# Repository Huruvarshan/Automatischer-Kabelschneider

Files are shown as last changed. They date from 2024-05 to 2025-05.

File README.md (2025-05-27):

# Automatischer Kabelschneider (Automatic Cable Cutter)

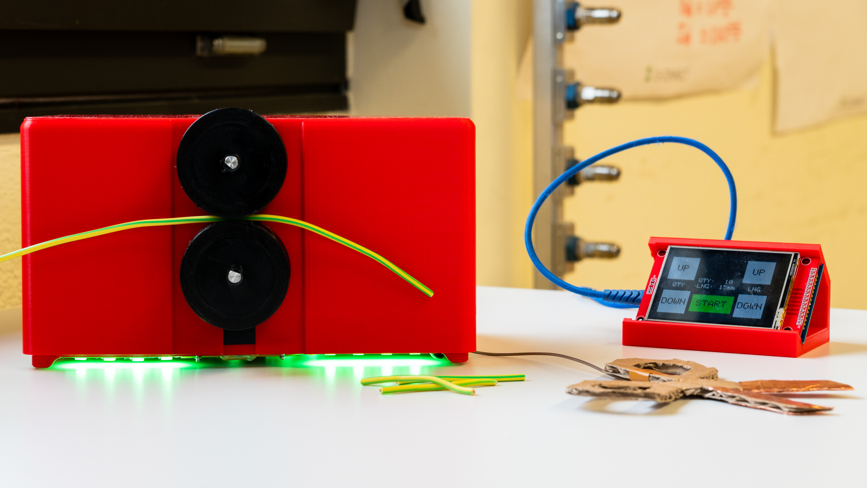
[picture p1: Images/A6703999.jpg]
Project in Action Automatic Cable Cutter


## Overview

The **Automatischer Kabelschneider** is an open-source, programmable device for automatically cutting cables and heat shrink tubes to precise lengths and quantities. Designed for makers, professionals, and hobbyists, it streamlines repetitive workshop tasks, ensuring accuracy, safety, and efficiency in cable and tube preparation.

This repository includes all hardware and software resources needed to build, assemble, and operate the device.

---

## Features

- **Programmable Length & Quantity:**  
  Set the desired length and number of pieces using capacitive buttons and an integrated display.

- **Precision Cutting:**  
  Delivers clean, accurate cuts suitable for various cable and tube diameters.

- **Material Flexibility:**  
  Supports cables, heat shrink tubes, and similar flexible materials.

- **Job Notification:**  
  Visual indicators (LEDs or beacons) signal job progress and completion.

- **Safety:**  
  Built-in overheat protection, a "SawStop"-style emergency system, and run-out sensors to prevent accidents.

---

## Repository Structure

```
Automatischer-Kabelschneider/
├── Hardware/
│   ├── PCB/           # KiCad PCB design files
│   ├── Mechanical/    # Mechanical design files (e.g., 3D models)
│   ├── BOM.md         # Bill of Materials
│   └── README.md      # Hardware documentation
├── Software/
│   ├── AKS_Program/   # Microcontroller firmware (ESP32)
│   │   └── README.md  # Software setup and usage
│   └── README.md      # Software structure and notes
├── Images/            # Project and schematic images
│   └── A6703971.JPG
└── README.md          # Project overview (this file)
```

---

## Getting Started

### 1. Hardware

- Manufacture and assemble the PCB and mechanical parts using files in `/Hardware`.
- Reference the Bill of Materials (`Hardware/BOM.md`) for required components.
- Follow detailed assembly instructions in `Hardware/README.md`.

### 2. Software

- The main firmware for the microcontroller (ESP32) is located in `Software/AKS_Program/`.
- See `Software/AKS_Program/README.md` for build, installation, and configuration steps.
- The firmware controls motors, sensors, and LED feedback, and communicates with the device interface.

### 3. Operation

- Use the device's capacitive interface to configure cut length and quantity.
- Start the automatic cutting process. LEDs provide real-time feedback.
- The machine stops automatically and alerts you when the job is complete.

---

## Documentation

- **Hardware Details:** [Hardware/README.md](Hardware/README.md)
- **Software Instructions:** [Software/AKS_Program/README.md](Software/AKS_Program/README.md)

---

## Contributing

Contributions, bug reports, and suggestions are welcome!  
Please open an issue or submit a pull request via GitHub.

---

## Safety & Disclaimer

- Always follow safety instructions and observe caution while operating the device.
- The authors are not responsible for any injury or damage resulting from use or misuse of this project.

---

## License

This project is licensed under the MIT License.  
See [LICENSE](LICENSE) for details.

---

**Let’s build better tools together!**

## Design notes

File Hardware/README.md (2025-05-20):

# Hardware Documentation

Welcome to the hardware section of the Automatischer Kabelschneider (Automatic Cable Cutter) project.

## PCB Design

- The PCB (Printed Circuit Board) design files are available here:  
  [./PCB/](Automatischer-Kabelschneider/Hardware/PCB/)
  
  a title

## Mechanical Design

- The mechanical design files can be found here:  
  [./Mechanical/](../Mechanical/)  

## Bill of Materials (BOM)

- A complete list of components required for the hardware build is available here:  
  [./BOM.md](./BOM.md)  

## Assembly Instructions

- Step-by-step instructions for assembling the hardware will be provided here.  

## Firmware

- The firmware for running the device is located in the main repository:  
  [../Firmware/](../Firmware/)

## Additional Notes

- Please check that all the referenced files and folders are present in this directory.
- For troubleshooting, questions, or contributions, please open an issue in the main repository.

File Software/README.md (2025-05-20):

# Automatic Cable Cutter – Software

## Overview

This directory contains the software for the Automatic Cable Cutter project.

- **Arduino File:** The Arduino file is intended exclusively for the display unit. It manages and controls the display and user interface.
- **AKS Program:** The AKS program is for the main unit of the cable cutter. It performs the main control functions for the cable cutting process.

## Structure

- `/Arduino/`  
  Code for the display unit (e.g., showing data, handling user input)
- `/AKS/`  
  Main program for controlling and automating the cable cutter

## Usage Notes

- Make sure to upload the Arduino firmware only to the display unit.
- The AKS program should be loaded onto the main control unit (e.g., microcontroller or control computer).
- Both programs are designed to work together, but are not interchangeable.

## Additional Information

- Please make changes or add features in separate branches and submit a pull request.
- If you have questions or encounter issues, create an issue in this repository.
- Documentation for hardware setup and wiring may be provided in additional files or the project Wiki.

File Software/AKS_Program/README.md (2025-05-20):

# AKS-Program

This directory contains the software for the Automatischer Kabelschneider (Automatic Cable Cutter).

## Requirements

- Download the `led-strip.h` library from the Espressif component registry: [led_strip v3.0.1](https://components.espressif.com/components/espressif/led_strip/versions/3.0.1)

## Overview

The code in this folder controls the automatic cable cutting process. Key features include:
- Interfacing with hardware components such as motors and sensors
- Controlling an LED strip for visual feedback
- Providing configuration options for cable length and quantity

## File Structure

- `main.c` (or similar): Main application logic for controlling the cable cutter
- `led-strip.h`: Required library for LED control (see above)
- Additional source and header files for hardware interface and user configuration

## Getting Started

1. Clone this repository.
2. Download and add `led-strip.h` to your project as described above.
3. Build and flash the firmware to your hardware using your preferred ESP32 development environment.

## Usage

- Configure your desired cable length and quantity in the software or via the user interface.
- Start the program to begin the automatic cutting process.
- The LED strip will provide status and progress feedback during operation.

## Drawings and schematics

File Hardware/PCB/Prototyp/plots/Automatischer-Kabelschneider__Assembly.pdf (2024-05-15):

J8 R⁶ | C¹³ | Q4 1 | 2 | 3 | 4 | 5 | 6 1 | 2 | 3 | 4 | 5 | 6 ABCD | ABCD Date: 2024-05-15 KiCad E.D.A. 8.0.2 Size: A4 | Rev: 1.0
File: Automatischer-Kabelschneider.kicad_pcb Sheet: AISLER Project ID: AOEPXYGU ¹⁰k R¹⁴ | 100n C³⁰ TestPoint_Small | TP¹³

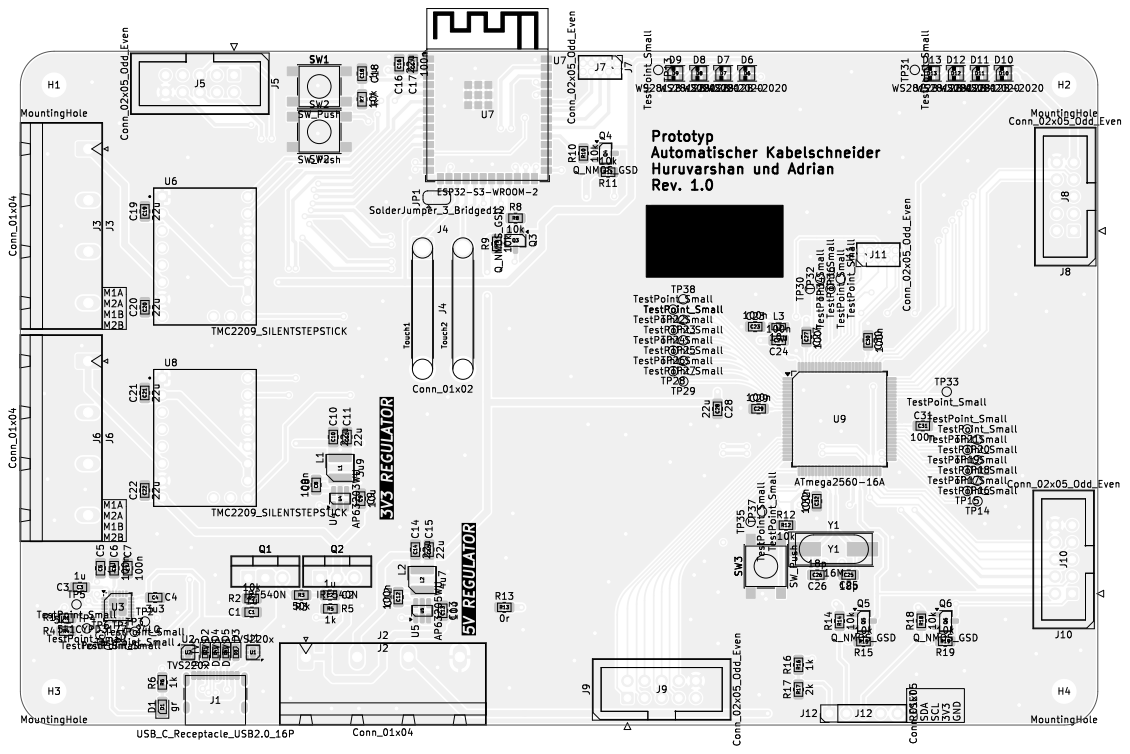
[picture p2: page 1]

1 | 2 | 3 | 4 | 5 | 6

A

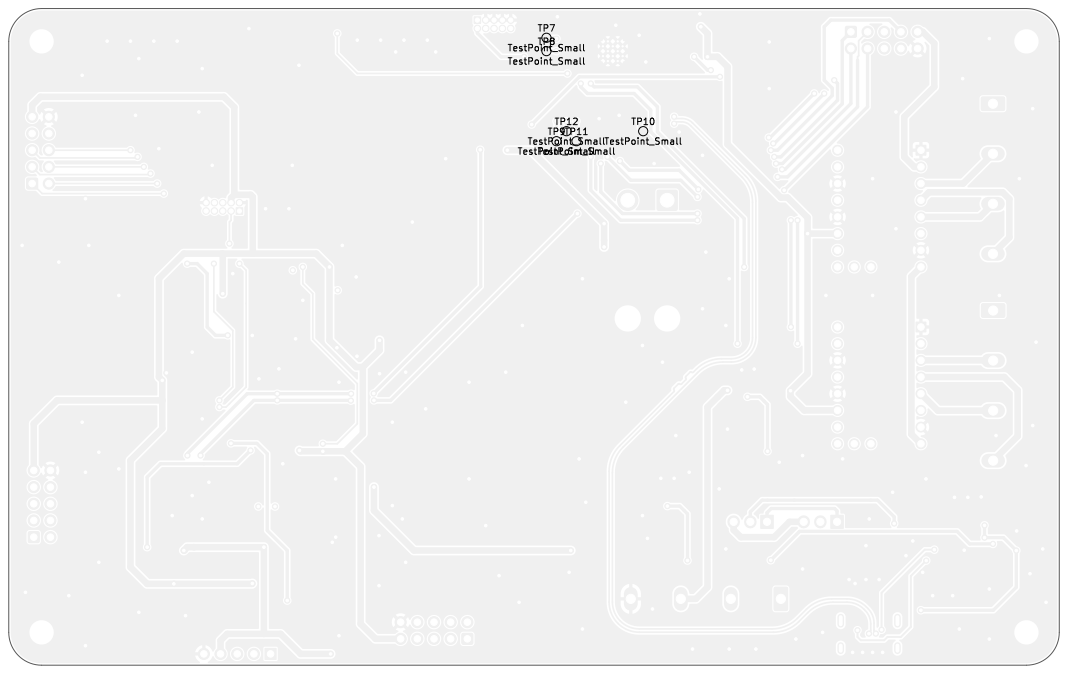
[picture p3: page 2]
D Date: 2024-05-15 KiCad; E.D.A. 8.0.2 Size: A4; Rev: 1.0; File: Automatischer-Kabelschneider.kicad_pcb Sheet: AISLER; Project; ID: AOEPXYGU; TestPoint_Small TP12 TestPoint_Small TP9TP11; TestPoint_Small TP10 TestPoint_Small TP8 TestPoint_Small TP7

Id: 1/1 Title: Prototyp

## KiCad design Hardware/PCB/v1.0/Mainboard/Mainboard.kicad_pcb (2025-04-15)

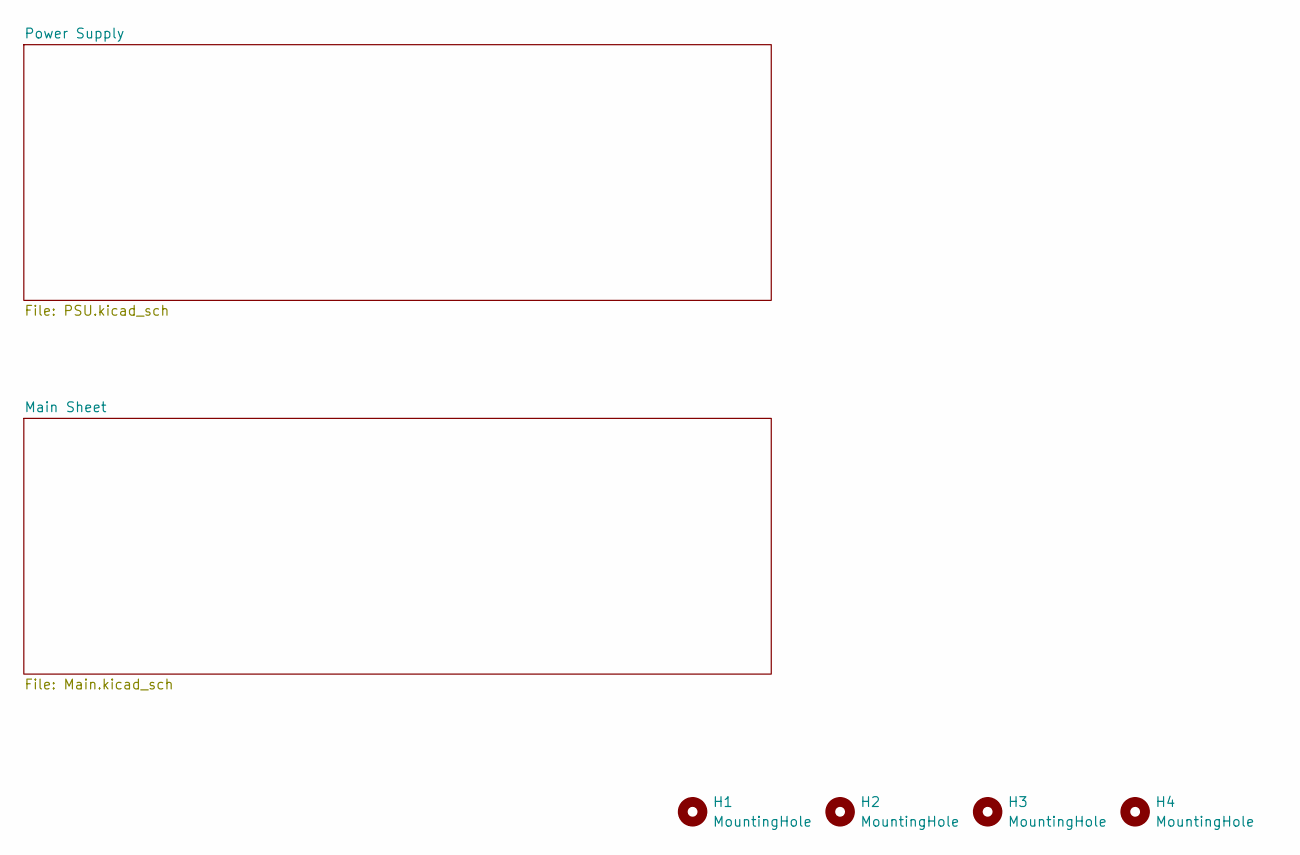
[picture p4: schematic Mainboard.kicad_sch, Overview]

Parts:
H1, H2, H3, H4: MountingHole; MountingHole_3.2mm_M3

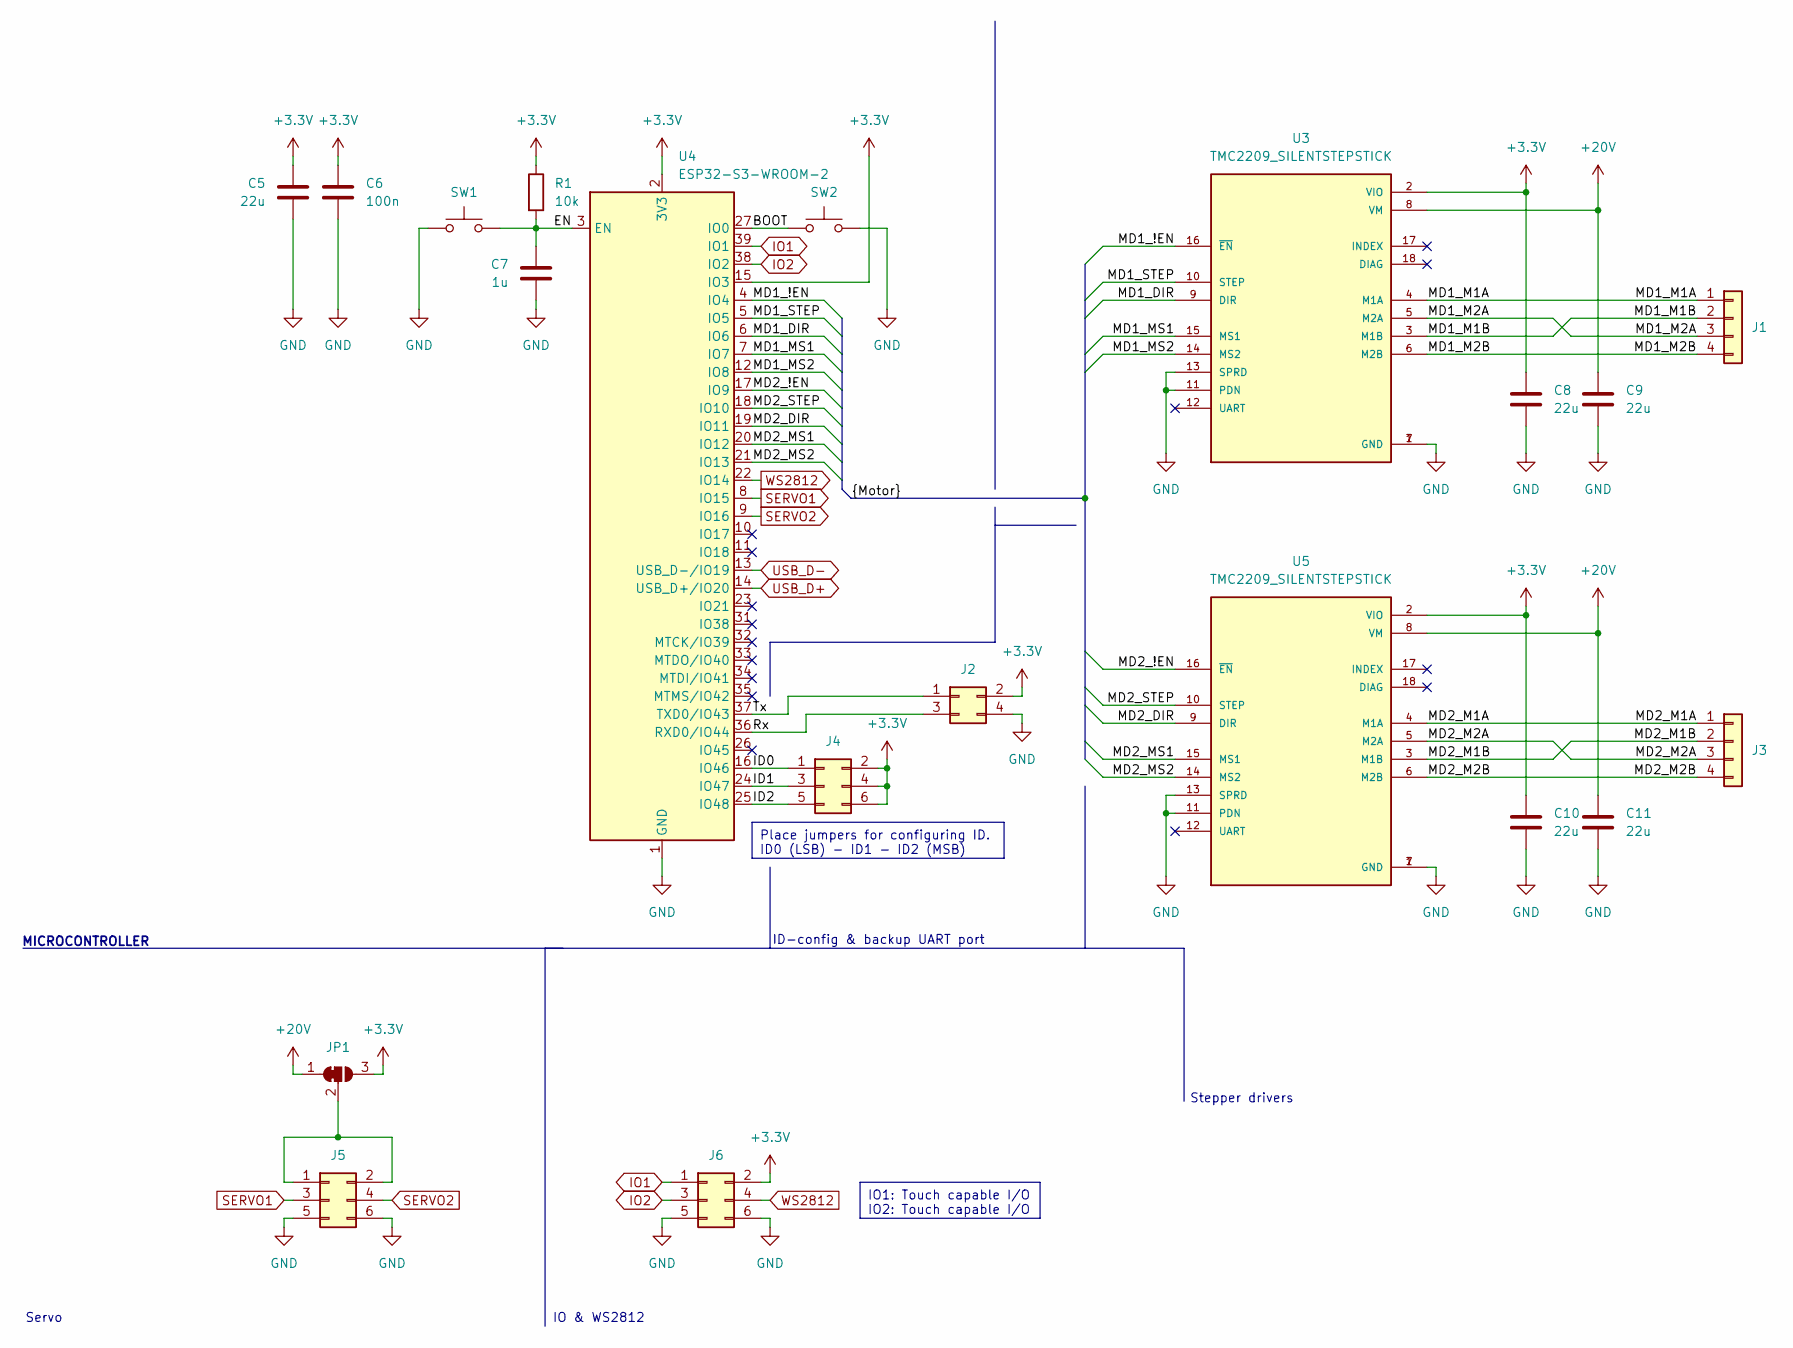
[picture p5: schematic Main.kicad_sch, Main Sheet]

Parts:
C5, C8, C9, C10, C11: 22u; C_0805_2012Metric
C6: 100n; C_0805_2012Metric
C7: 1u; C_0805_2012Metric
J1, J3: Conn_01x04; PhoenixContact_MC_1,5_4-G-3.81_1x04_P3.81mm_Horizontal
J2: Conn_02x02_Odd_Even; PinHeader_2x02_P2.54mm_Vertical
J4, J5, J6: Conn_02x03_Odd_Even; PinHeader_2x03_P2.54mm_Vertical
JP1: SolderJumper_3_Bridged12; SolderJumper-3_P1.3mm_Bridged12_RoundedPad1.0x1.5mm
R1: 10k; R_0805_2012Metric
SW1, SW2: SW_Push; SW_Push_1P1T_NO_6x6mm_H9.5mm
U3, U5: TMC2209_SILENTSTEPSTICK; MODULE_TMC2209_SILENTSTEPSTICK; PARTREV 1.20
U4: ESP32-S3-WROOM-2

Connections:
+3.3V: C5.1, C6.1, C8.1, C10.1, J2.2, J4.2, J4.4, J4.6, J6.2, JP1.3 (B), R1.1, U3.2 (VIO), U4.2 (3V3), U4.15 (IO3), U5.2 (VIO); also elsewhere on the board
+20V: C9.1, C11.1, JP1.1 (A), U3.8 (VM), U5.8 (VM); also elsewhere on the board
/Main Sheet/BOOT: SW2.1, U4.27 (IO0)
/Main Sheet/EN: C7.1, R1.2, SW1.2, U4.3 (EN)
/Main Sheet/ID0: J4.1, U4.16 (IO46)
/Main Sheet/ID1: J4.3, U4.24 (IO47)
/Main Sheet/ID2: J4.5, U4.25 (IO48)
/Main Sheet/MD1_!EN: U3.16 (~EN), U4.4 (IO4)
/Main Sheet/MD1_DIR: U3.9 (DIR), U4.6 (IO6)
/Main Sheet/MD1_M1A: J1.1, U3.4 (M1A)
/Main Sheet/MD1_M1B: J1.2, U3.3 (M1B)
/Main Sheet/MD1_M2A: J1.3, U3.5 (M2A)
/Main Sheet/MD1_M2B: J1.4, U3.6 (M2B)
/Main Sheet/MD1_MS1: U3.15 (MS1), U4.7 (IO7)
/Main Sheet/MD1_MS2: U3.14 (MS2), U4.12 (IO8)
/Main Sheet/MD1_STEP: U3.10 (STEP), U4.5 (IO5)
/Main Sheet/MD2_!EN: U4.17 (IO9), U5.16 (~EN)
/Main Sheet/MD2_DIR: U4.19 (IO11), U5.9 (DIR)
/Main Sheet/MD2_M1A: J3.1, U5.4 (M1A)
/Main Sheet/MD2_M1B: J3.2, U5.3 (M1B)
/Main Sheet/MD2_M2A: J3.3, U5.5 (M2A)
/Main Sheet/MD2_M2B: J3.4, U5.6 (M2B)
/Main Sheet/MD2_MS1: U4.20 (IO12), U5.15 (MS1)
/Main Sheet/MD2_MS2: U4.21 (IO13), U5.14 (MS2)
/Main Sheet/MD2_STEP: U4.18 (IO10), U5.10 (STEP)
/Main Sheet/Rx: J2.3, U4.36 (RXD0/IO44)
/Main Sheet/Tx: J2.1, U4.37 (TXD0/IO43)
GND: C5.2, C6.2, C7.2, C8.2, C9.2, C10.2, C11.2, J2.4, J5.5, J5.6, J6.5, J6.6, SW1.1, SW2.2, U3.1 (GND), U3.7 (GND), U3.11 (PDN), U3.13 (SPRD), U4.1 (GND), U4.40 (GND), U4.41 (GND), U5.1 (GND), U5.7 (GND), U5.11 (PDN), U5.13 (SPRD); also elsewhere on the board
IO1: J6.1, U4.39 (IO1)
IO2: J6.3, U4.38 (IO2)
unnamed: J5.1, J5.2, JP1.2 (C)
SERVO1: J5.3, U4.8 (IO15)
SERVO2: J5.4, U4.9 (IO16)
USB_D+: U4.14 (USB_D+/IO20); also elsewhere on the board
USB_D-: U4.13 (USB_D-/IO19); also elsewhere on the board
WS2812: J6.4, U4.22 (IO14)

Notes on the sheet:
IO1: Touch capable I/O IO2: Touch capable I/O
Place jumpers for configuring ID. ID0 (LSB) - ID1 - ID2 (MSB)
IO & WS2812
Stepper drivers
Servo
ID-config & backup UART port
MICROCONTROLLER

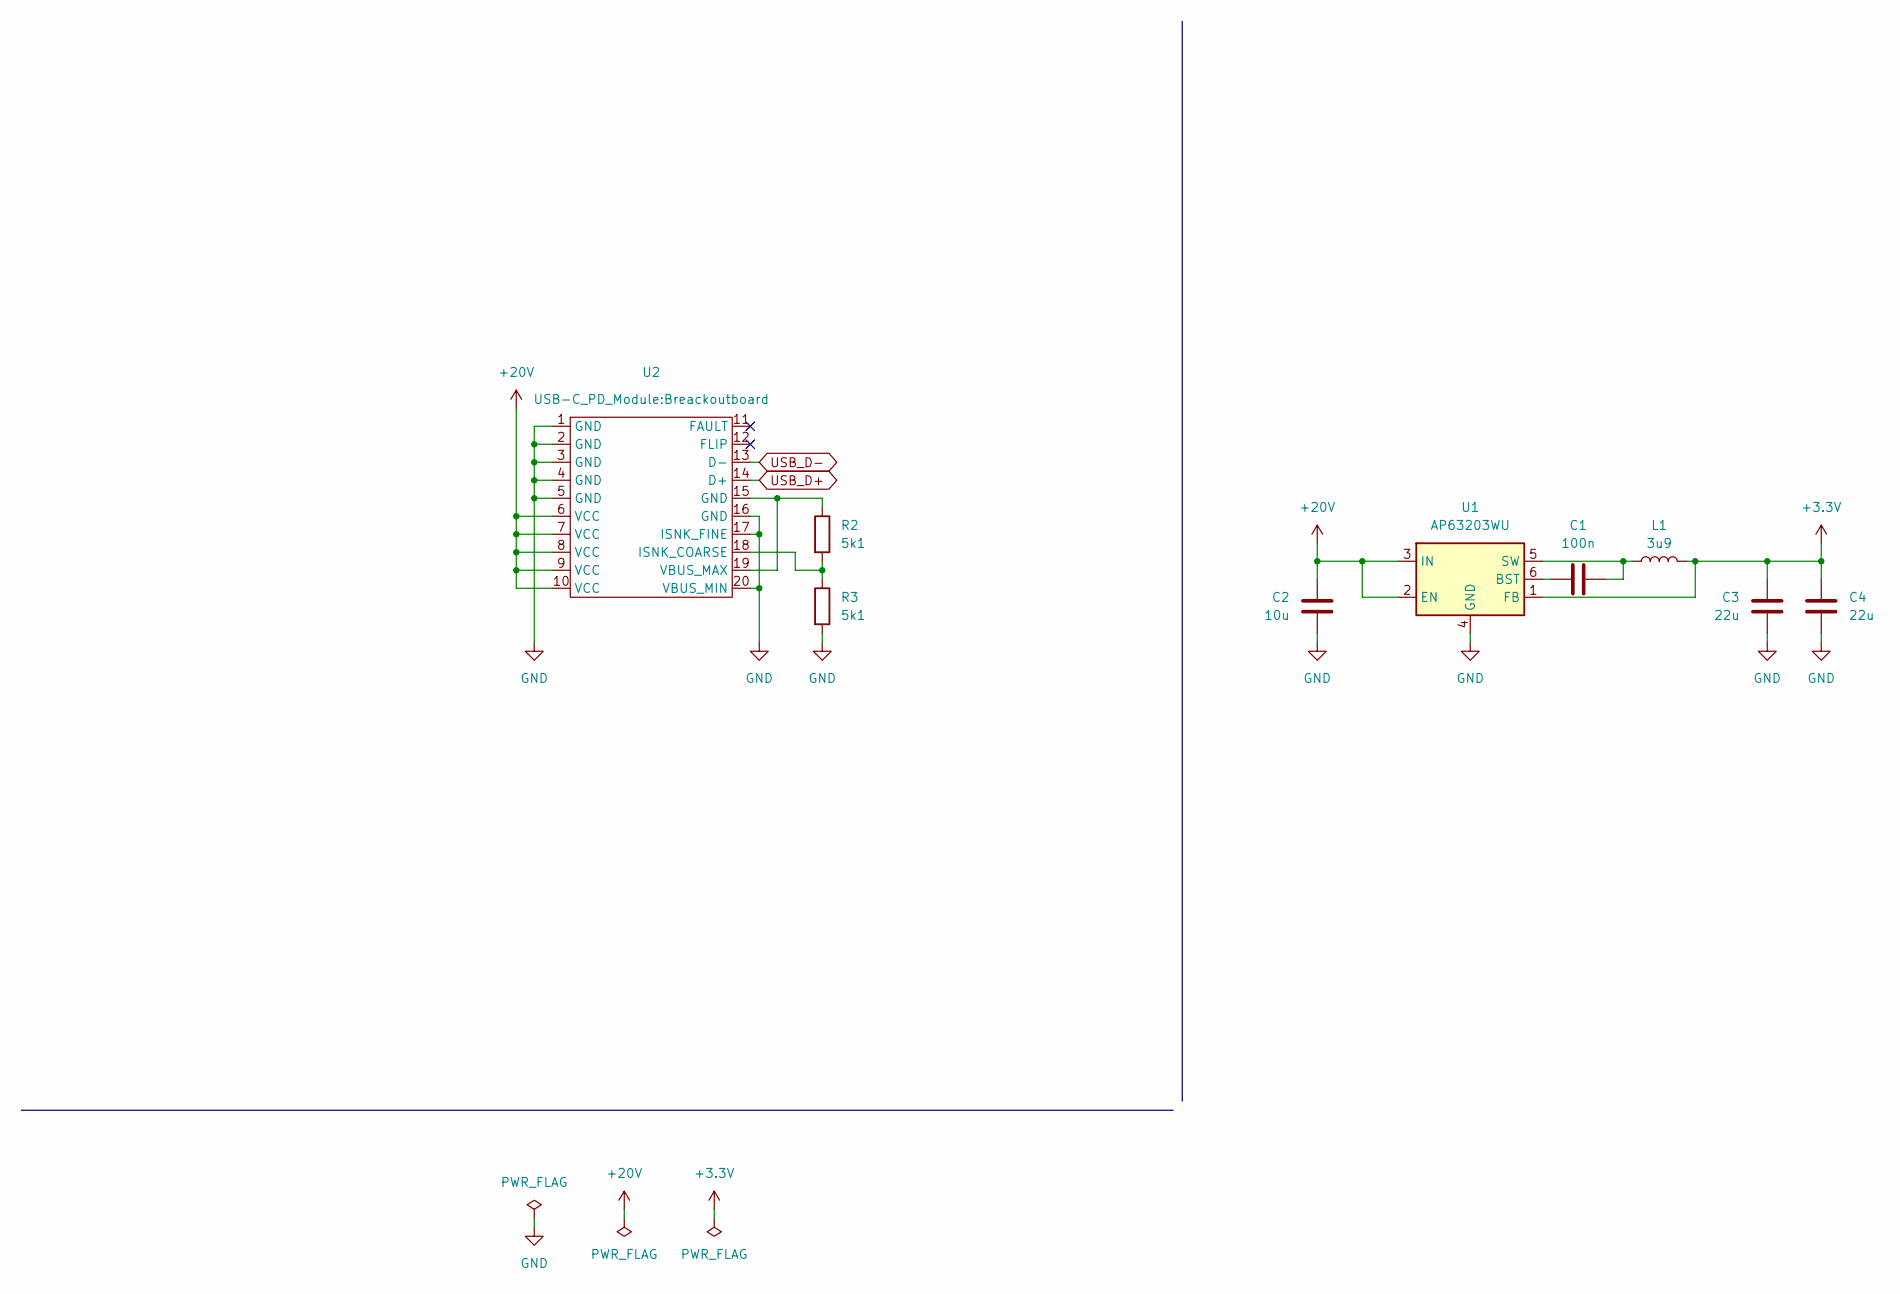
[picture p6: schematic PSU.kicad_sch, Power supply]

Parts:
C1: 100n; C_0805_2012Metric
C2: 10u; C_0805_2012Metric
C3, C4: 22u; C_0805_2012Metric
L1: 3u9; L_Wurth_WE-LQSH-4020
R2, R3: 5k1; R_0805_2012Metric
U1: AP63203WU; TSOT-23-6
U2: Breackoutboard

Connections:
+3.3V: C3.1, C4.1, L1.2, U1.1 (FB); also elsewhere on the board
+20V: C2.1, U1.2 (EN), U1.3 (IN), U2.6 (VCC), U2.7 (VCC), U2.8 (VCC), U2.9 (VCC), U2.10 (VCC); also elsewhere on the board
GND: C2.2, C3.2, C4.2, R3.2, U1.4 (GND), U2.1 (GND), U2.2 (GND), U2.3 (GND), U2.4 (GND), U2.5 (GND), U2.16 (GND), U2.17 (ISNK_FINE), U2.20 (VBUS_MIN); also elsewhere on the board
unnamed: C1.2, U1.6 (BST)
unnamed: C1.1, L1.1, U1.5 (SW)
unnamed: R2.2, R3.1, U2.18 (ISNK_COARSE)
unnamed: R2.1, U2.15 (GND), U2.19 (VBUS_MAX)
USB_D+: U2.14 (D+); also elsewhere on the board
USB_D-: U2.13 (D-); also elsewhere on the board

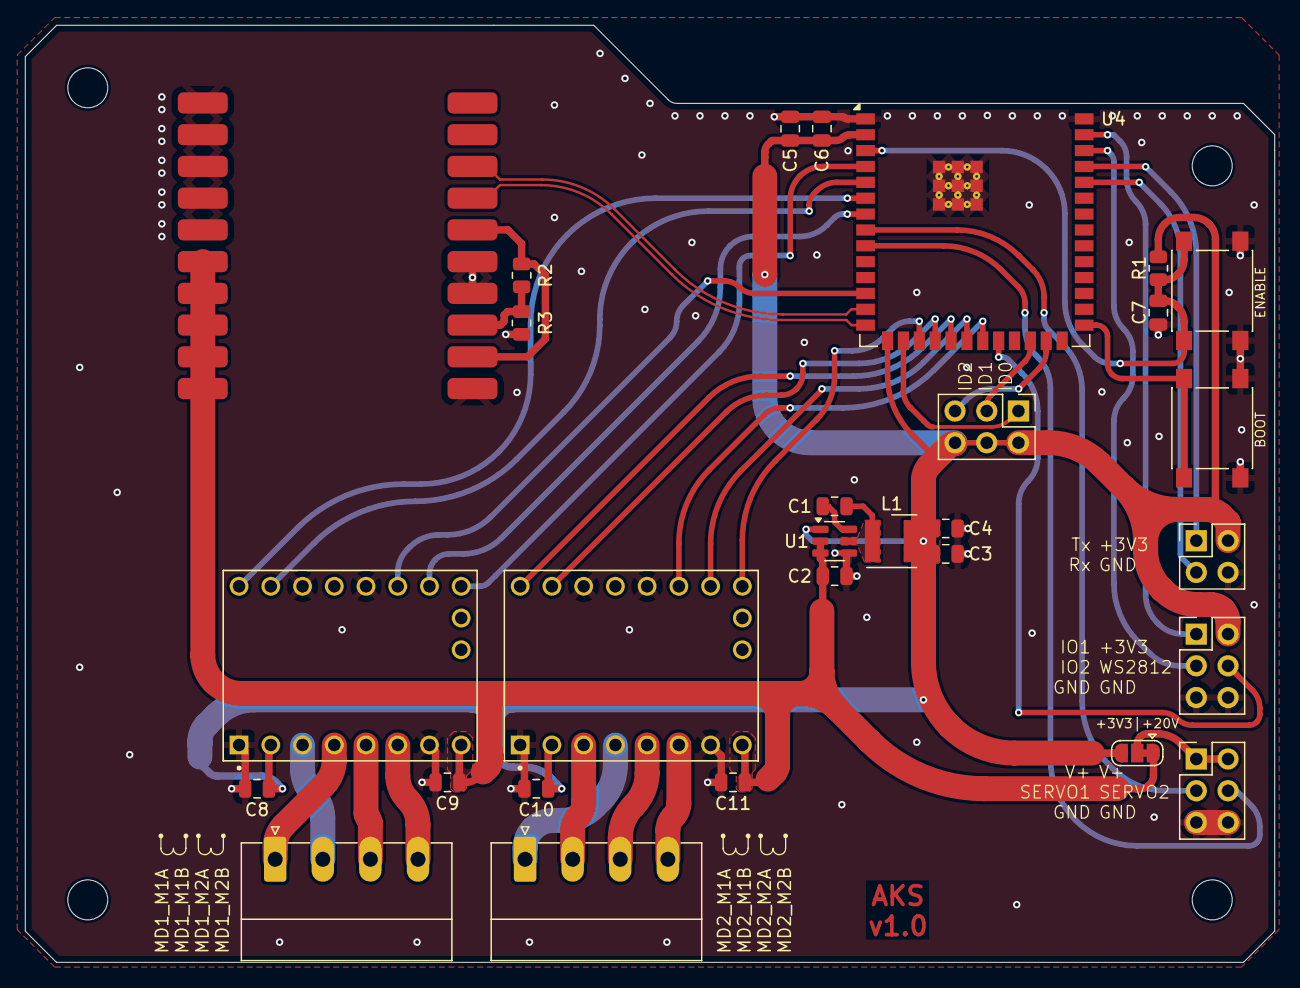
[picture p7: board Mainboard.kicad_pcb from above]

Board: 2 copper layers, 100.0 x 75.0 mm, 33 parts (0 on the bottom side), 40 nets.

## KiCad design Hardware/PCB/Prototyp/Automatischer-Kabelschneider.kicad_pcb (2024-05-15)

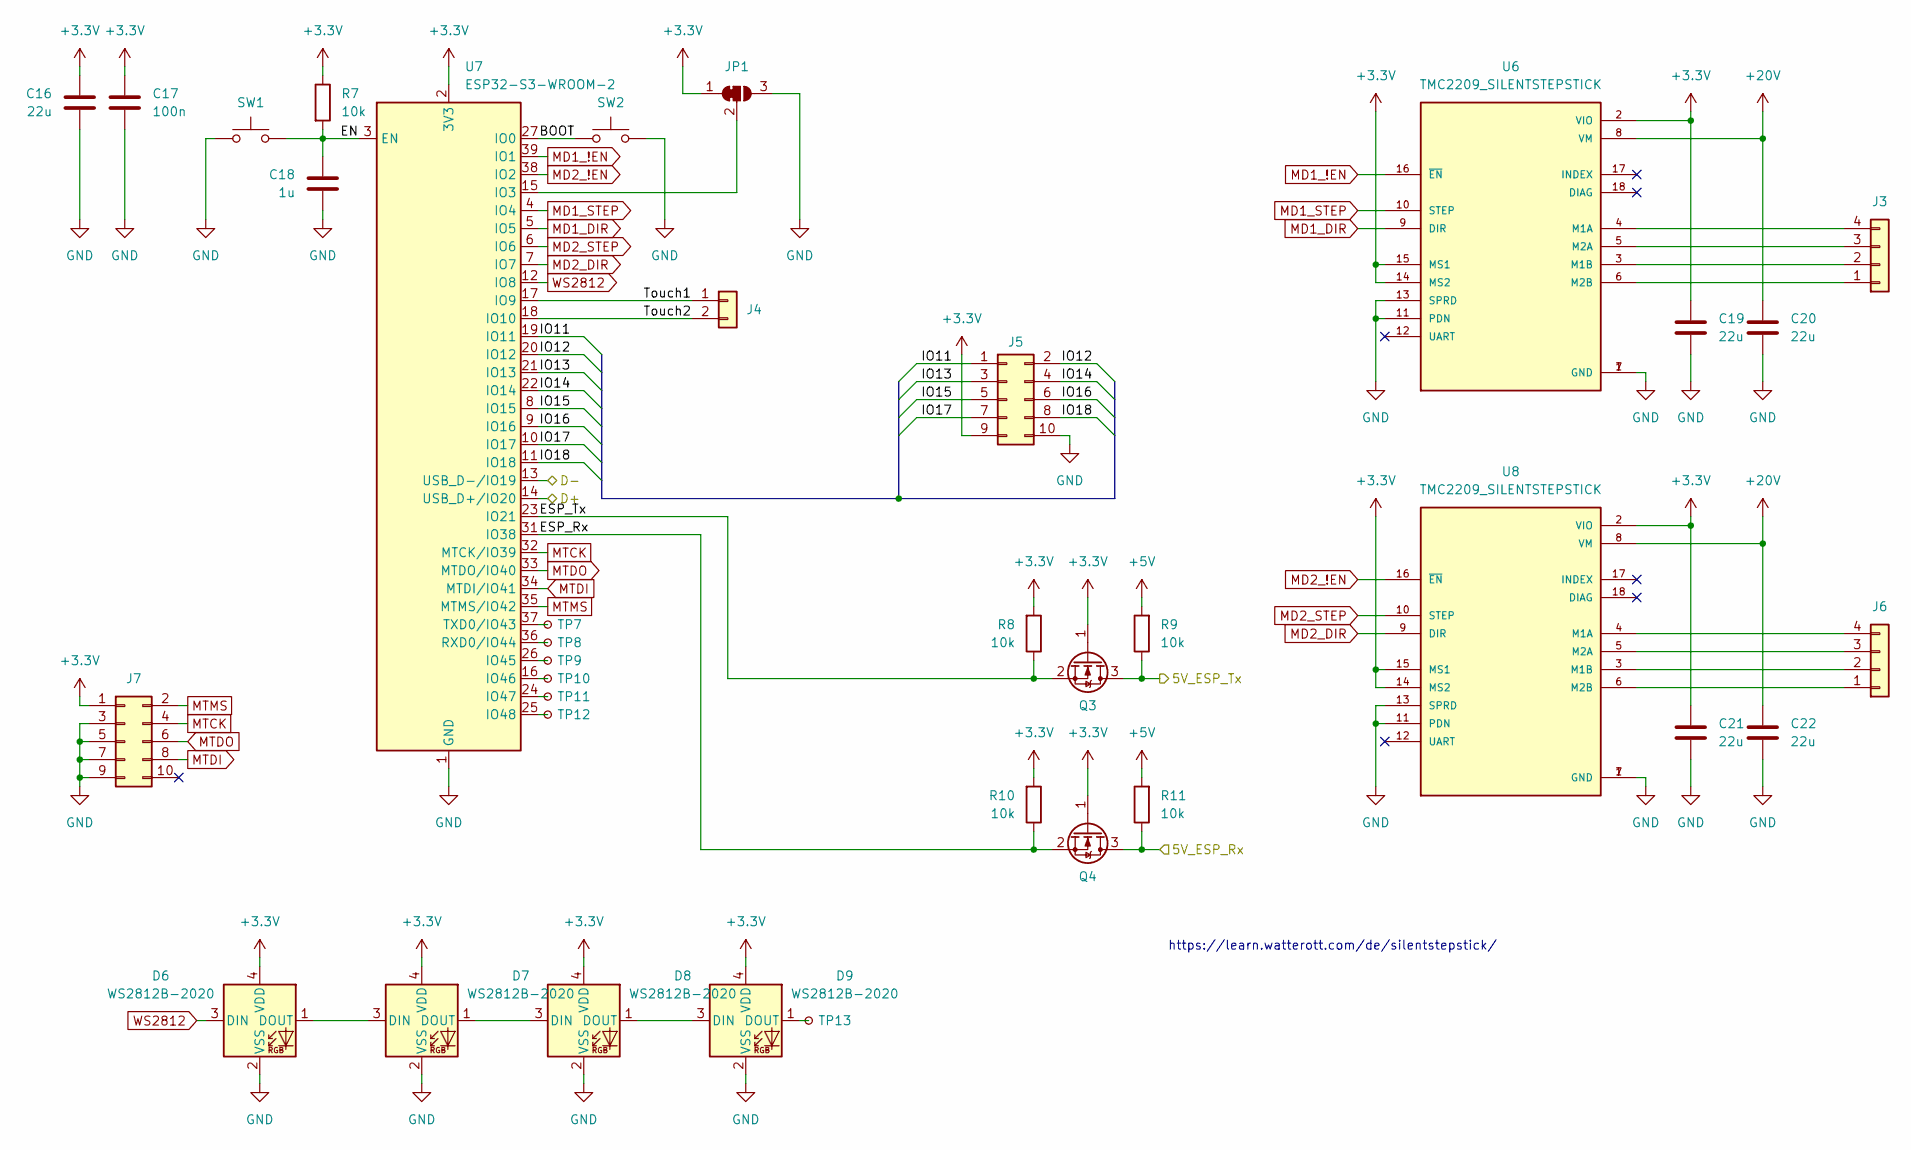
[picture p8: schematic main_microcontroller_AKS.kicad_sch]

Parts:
C16, C19, C20, C21, C22: 22u; C_0805_2012Metric
C17: 100n; C_0805_2012Metric
C18: 1u; C_0805_2012Metric
D6, D7, D8, D9: WS2812B-2020; LED_WS2812B-2020_PLCC4_2.0x2.0mm
J3, J6: Conn_01x04; PhoenixContact_GMSTBA_2,5_4-G-7,62_1x04_P7.62mm_Horizontal
J4: Conn_01x02; SolderWire-1.5sqmm_1x02_P6mm_D1.7mm_OD3mm_Relief
J5: Conn_02x05_Odd_Even; IDC-Header_2x05_P2.54mm_Vertical
J7: Conn_02x05_Odd_Even; PinHeader_2x05_P1.27mm_Vertical
JP1: SolderJumper_3_Bridged12; SolderJumper-3_P1.3mm_Bridged12_RoundedPad1.0x1.5mm
Q3, Q4: Q_NMOS_GSD; TSOT-23
R7, R8, R9, R10, R11: 10k; R_0805_2012Metric
SW1, SW2: SW_Push; SW_Push_1P1T_NO_6x6mm_H9.5mm
TP7, TP8, TP9, TP10, TP11, TP12, TP13: TestPoint_Small; TestPoint_Pad_D1.0mm
U6, U8: TMC2209_SILENTSTEPSTICK; MODULE_TMC2209_SILENTSTEPSTICK; PARTREV 1.20
U7: ESP32-S3-WROOM-2

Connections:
+3.3V: C16.1, C17.1, C19.1, C21.1, D6.4 (VDD), D7.4 (VDD), D8.4 (VDD), D9.4 (VDD), J5.9, J7.1, JP1.1 (A), Q3.1 (G), Q4.1 (G), R7.1, R8.2, R10.2, U6.2 (VIO), U6.14 (MS2), U6.15 (MS1), U7.2 (3V3), U8.2 (VIO), U8.14 (MS2), U8.15 (MS1); also elsewhere on the board
+5V: R9.2, R11.2; also elsewhere on the board
/Main Microcontroller/BOOT: SW2.1, U7.27 (IO0)
/Main Microcontroller/D+: U7.14 (USB_D+/IO20); also elsewhere on the board
/Main Microcontroller/D-: U7.13 (USB_D-/IO19); also elsewhere on the board
/Main Microcontroller/EN: C18.1, R7.2, SW1.2, U7.3 (EN)
/Main Microcontroller/ESP_Rx: Q4.2 (S), R10.1, U7.31 (IO38)
/Main Microcontroller/ESP_Tx: Q3.2 (S), R8.1, U7.23 (IO21)
/Main Microcontroller/IO11: J5.1, U7.19 (IO11)
/Main Microcontroller/IO12: J5.2, U7.20 (IO12)
/Main Microcontroller/IO13: J5.3, U7.21 (IO13)
/Main Microcontroller/IO14: J5.4, U7.22 (IO14)
/Main Microcontroller/IO15: J5.5, U7.8 (IO15)
/Main Microcontroller/IO16: J5.6, U7.9 (IO16)
/Main Microcontroller/IO17: J5.7, U7.10 (IO17)
/Main Microcontroller/IO18: J5.8, U7.11 (IO18)
/Main Microcontroller/Touch1: J4.1, U7.17 (IO9)
/Main Microcontroller/Touch2: J4.2, U7.18 (IO10)
/Slave Microcontroller/ATMEGA_Rx: Q3.3 (D), R9.1; also elsewhere on the board
/Slave Microcontroller/ATMEGA_Tx: Q4.3 (D), R11.1; also elsewhere on the board
GND: C16.2, C17.2, C18.2, C19.2, C20.2, C21.2, C22.2, D6.2 (VSS), D7.2 (VSS), D8.2 (VSS), D9.2 (VSS), J5.10, J7.3, J7.5, J7.7, J7.9, JP1.3 (B), SW1.1, SW2.2, U6.1 (GND), U6.7 (GND), U6.11 (PDN), U6.13 (SPRD), U7.1 (GND), U7.40 (GND), U7.41 (GND), U8.1 (GND), U8.7 (GND), U8.11 (PDN), U8.13 (SPRD); also elsewhere on the board
MD1_!EN: U6.16 (~EN), U7.39 (IO1)
MD1_DIR: U6.9 (DIR), U7.5 (IO5)
MD1_STEP: U6.10 (STEP), U7.4 (IO4)
MD2_!EN: U7.38 (IO2), U8.16 (~EN)
MD2_DIR: U7.7 (IO7), U8.9 (DIR)
MD2_STEP: U7.6 (IO6), U8.10 (STEP)
MTCK: J7.4, U7.32 (MTCK/IO39)
MTDI: J7.8, U7.34 (MTDI/IO41)
MTDO: J7.6, U7.33 (MTDO/IO40)
MTMS: J7.2, U7.35 (MTMS/IO42)
unnamed: D6.1 (DOUT), D7.3 (DIN)
unnamed: D7.1 (DOUT), D8.3 (DIN)
unnamed: D8.1 (DOUT), D9.3 (DIN)
unnamed: D9.1 (DOUT), TP13.1
unnamed: J3.1, U6.6 (M2B)
unnamed: J3.2, U6.3 (M1B)
unnamed: J3.3, U6.5 (M2A)
unnamed: J3.4, U6.4 (M1A)
unnamed: J6.1, U8.6 (M2B)
unnamed: J6.2, U8.3 (M1B)
unnamed: J6.3, U8.5 (M2A)
unnamed: J6.4, U8.4 (M1A)
unnamed: JP1.2 (C), U7.15 (IO3)
unnamed: TP9.1, U7.26 (IO45)
unnamed: TP10.1, U7.16 (IO46)
unnamed: TP11.1, U7.24 (IO47)
unnamed: TP12.1, U7.25 (IO48)
unnamed: TP8.1, U7.36 (RXD0/IO44)
unnamed: TP7.1, U7.37 (TXD0/IO43)
WS2812: D6.3 (DIN), U7.12 (IO8)

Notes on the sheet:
https://learn.watterott.com/de/silentstepstick/

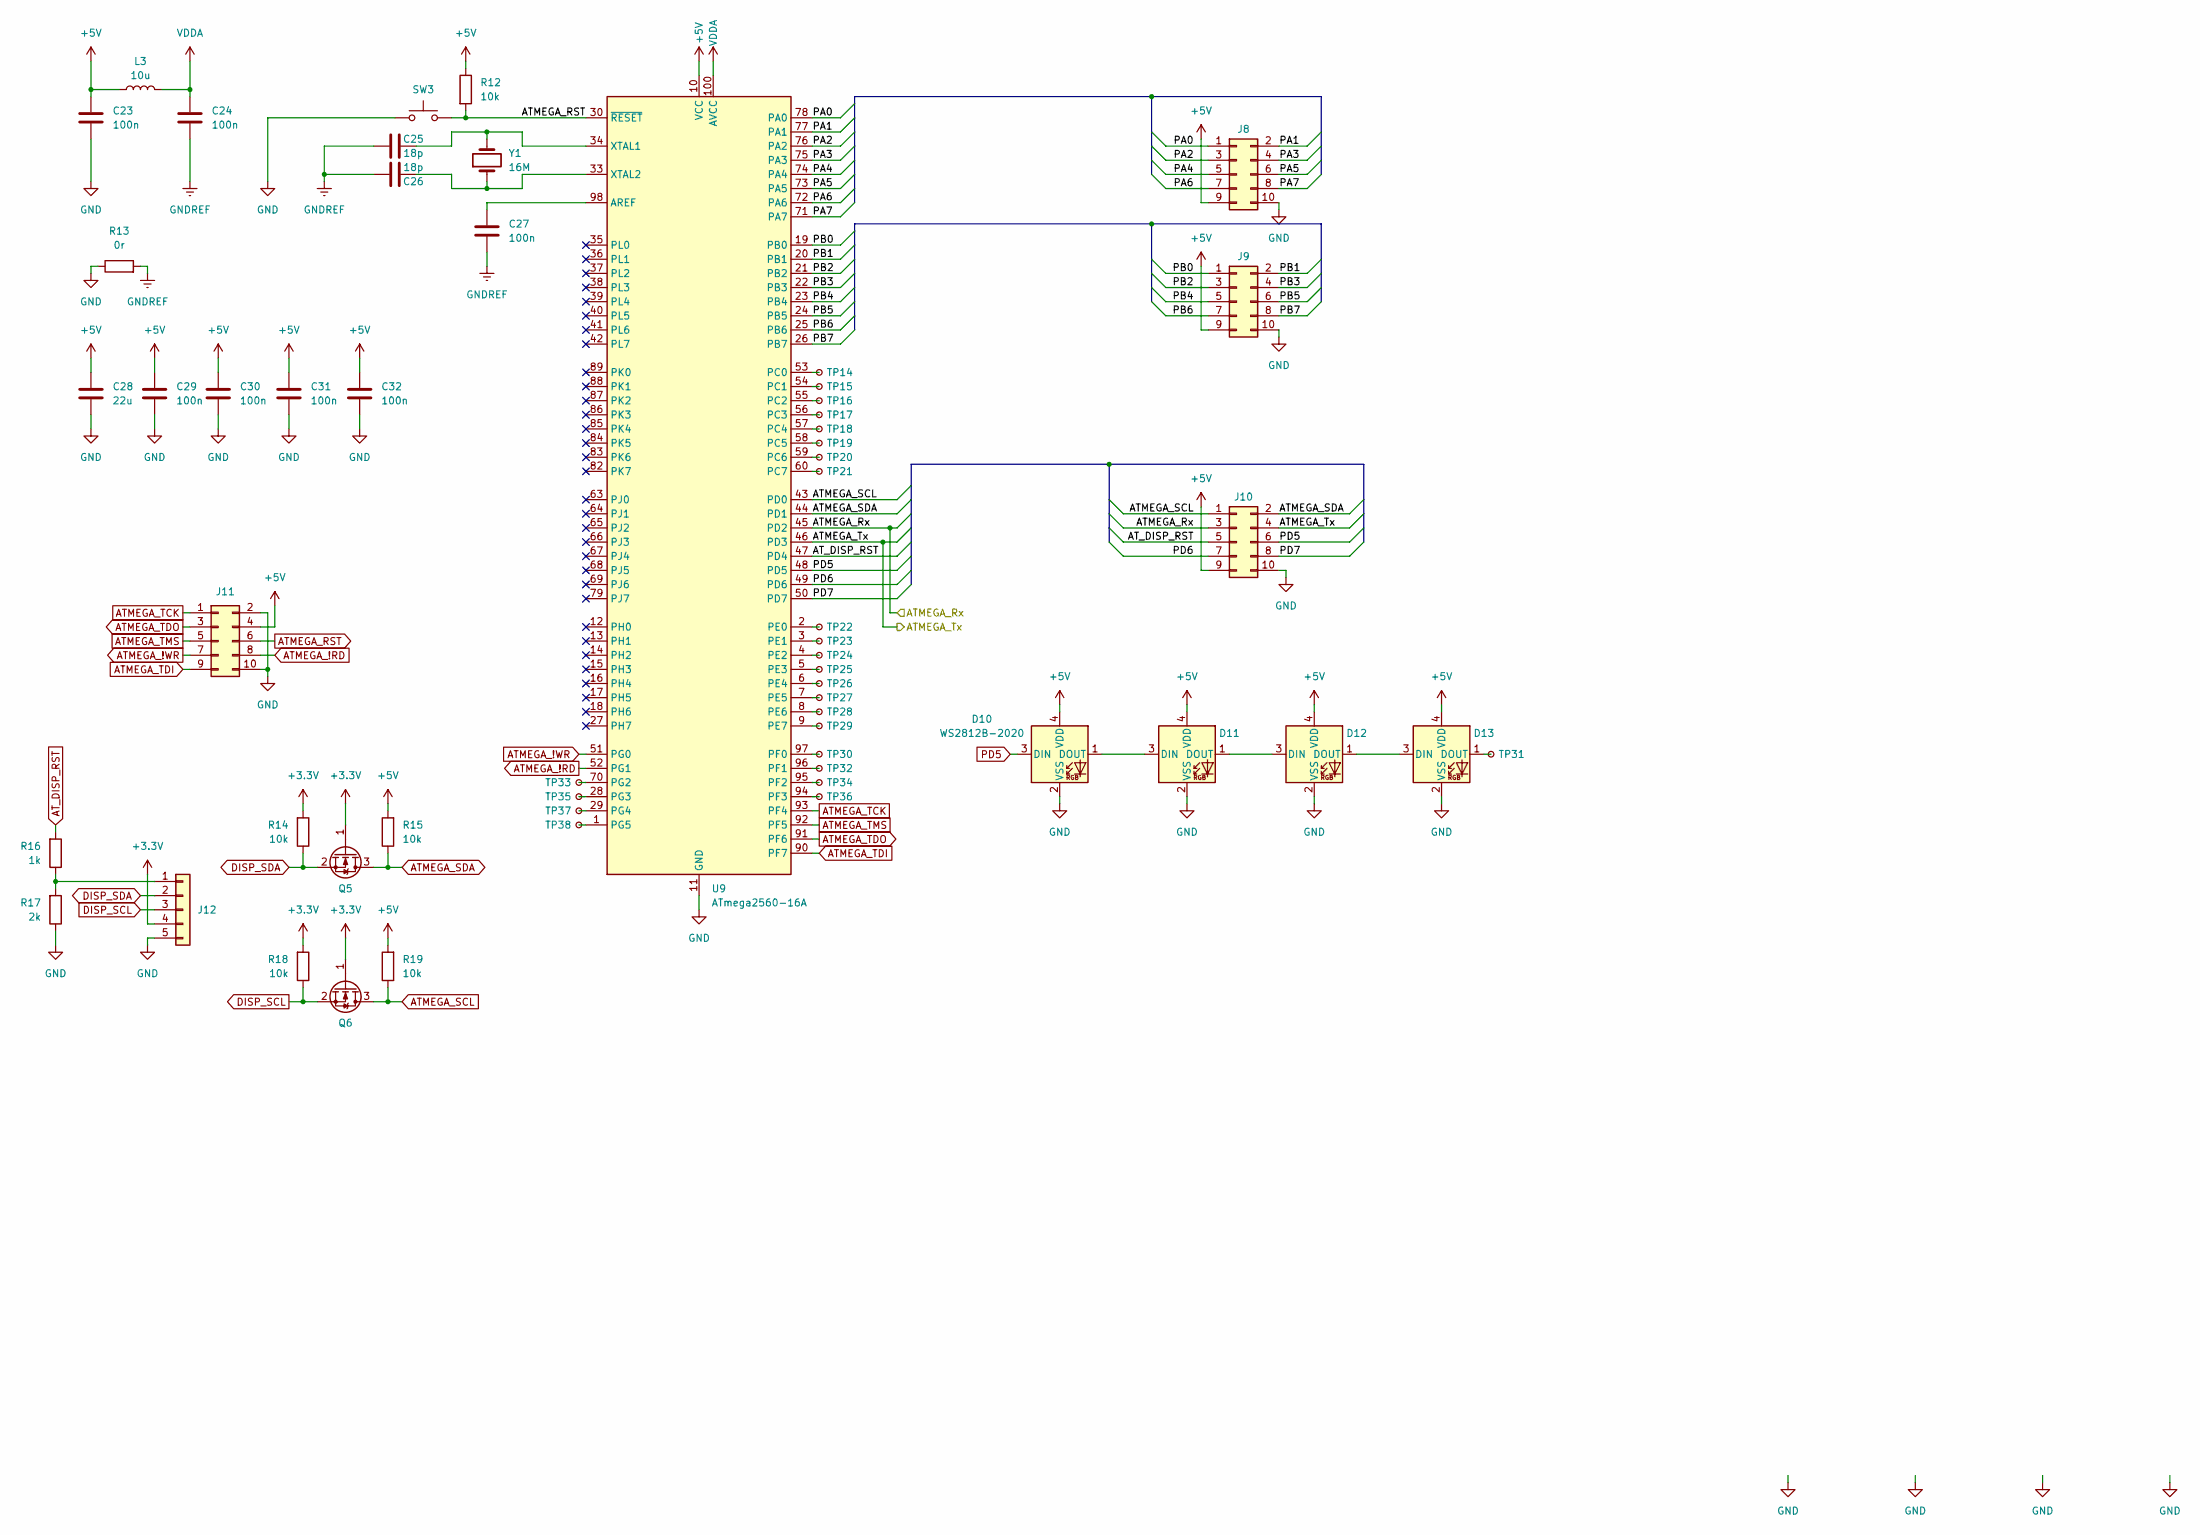
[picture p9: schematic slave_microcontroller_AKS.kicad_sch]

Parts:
C23, C24, C27, C29, C30, C31, C32: 100n; C_0805_2012Metric
C25, C26: 18p; C_0805_2012Metric
C28: 22u; C_0805_2012Metric
D10, D11, D12, D13: WS2812B-2020; LED_WS2812B-2020_PLCC4_2.0x2.0mm
J8, J9, J10: Conn_02x05_Odd_Even; IDC-Header_2x05_P2.54mm_Vertical
J11: Conn_02x05_Odd_Even; PinHeader_2x05_P1.27mm_Vertical
J12: Conn_01x05; PinHeader_1x05_P2.54mm_Vertical
L3: 10u; L_0805_2012Metric
Q5, Q6: Q_NMOS_GSD; TSOT-23
R12, R14, R15, R18, R19: 10k; R_0805_2012Metric
R13: 0r; R_0805_2012Metric
R16: 1k; R_0805_2012Metric
R17: 2k; R_0805_2012Metric
SW3: SW_Push; SW_Push_1P1T_NO_6x6mm_H9.5mm
TP14, TP15, TP16, TP17, TP18, TP19, TP20, TP21, TP22, TP23, TP24, TP25, TP26, TP27, TP28, TP29, TP30, TP31, TP32, TP33, TP34, TP35, TP36, TP37, TP38: TestPoint_Small; TestPoint_Pad_D1.0mm
U9: ATmega2560-16A; TQFP-100_14x14mm_P0.5mm
Y1: 16M; Crystal_SMD_HC49-SD

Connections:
+3.3V: J12.4, Q5.1 (G), Q6.1 (G), R14.2, R18.2; also elsewhere on the board
+5V: C23.1, C28.1, C29.1, C30.1, C31.1, C32.1, D10.4 (VDD), D11.4 (VDD), D12.4 (VDD), D13.4 (VDD), J8.9, J9.9, J10.9, J11.4, L3.1, R12.1, R15.2, R19.2, U9.10 (VCC), U9.31 (VCC), U9.61 (VCC), U9.80 (VCC); also elsewhere on the board
/Slave Microcontroller/ATMEGA_Rx: J10.3, U9.45 (PD2); also elsewhere on the board
/Slave Microcontroller/ATMEGA_Tx: J10.4, U9.46 (PD3); also elsewhere on the board
/Slave Microcontroller/PA0: J8.1, U9.78 (PA0)
/Slave Microcontroller/PA1: J8.2, U9.77 (PA1)
/Slave Microcontroller/PA2: J8.3, U9.76 (PA2)
/Slave Microcontroller/PA3: J8.4, U9.75 (PA3)
/Slave Microcontroller/PA4: J8.5, U9.74 (PA4)
/Slave Microcontroller/PA5: J8.6, U9.73 (PA5)
/Slave Microcontroller/PA6: J8.7, U9.72 (PA6)
/Slave Microcontroller/PA7: J8.8, U9.71 (PA7)
/Slave Microcontroller/PB0: J9.1, U9.19 (PB0)
/Slave Microcontroller/PB1: J9.2, U9.20 (PB1)
/Slave Microcontroller/PB2: J9.3, U9.21 (PB2)
/Slave Microcontroller/PB3: J9.4, U9.22 (PB3)
/Slave Microcontroller/PB4: J9.5, U9.23 (PB4)
/Slave Microcontroller/PB5: J9.6, U9.24 (PB5)
/Slave Microcontroller/PB6: J9.7, U9.25 (PB6)
/Slave Microcontroller/PB7: J9.8, U9.26 (PB7)
/Slave Microcontroller/PD6: J10.7, U9.49 (PD6)
/Slave Microcontroller/PD7: J10.8, U9.50 (PD7)
ATMEGA_!RD: J11.8, U9.52 (PG1)
ATMEGA_!WR: J11.7, U9.51 (PG0)
ATMEGA_RST: J11.6, R12.2, SW3.2, U9.30 (~RESET)
ATMEGA_SCL: J10.1, Q6.3 (D), R19.1, U9.43 (PD0)
ATMEGA_SDA: J10.2, Q5.3 (D), R15.1, U9.44 (PD1)
ATMEGA_TCK: J11.1, U9.93 (PF4)
ATMEGA_TDI: J11.9, U9.90 (PF7)
ATMEGA_TDO: J11.3, U9.91 (PF6)
ATMEGA_TMS: J11.5, U9.92 (PF5)
AT_DISP_RST: J10.5, R16.2, U9.47 (PD4)
DISP_SCL: J12.3, Q6.2 (S), R18.1
DISP_SDA: J12.2, Q5.2 (S), R14.1
GND: C23.2, C28.2, C29.2, C30.2, C31.2, C32.2, D10.2 (VSS), D11.2 (VSS), D12.2 (VSS), D13.2 (VSS), J8.10, J9.10, J10.10, J11.2, J11.10, J12.5, R13.1, R17.1, SW3.1, U9.11 (GND), U9.32 (GND), U9.62 (GND), U9.81 (GND), U9.99 (GND); also elsewhere on the board
GNDREF: C24.2, C25.1, C26.1, C27.2, R13.2
unnamed: D10.1 (DOUT), D11.3 (DIN)
unnamed: D11.1 (DOUT), D12.3 (DIN)
unnamed: D12.1 (DOUT), D13.3 (DIN)
unnamed: D13.1 (DOUT), TP31.1
unnamed: J12.1, R16.1, R17.2
unnamed: C27.1, U9.98 (AREF)
unnamed: TP14.1, U9.53 (PC0)
unnamed: TP15.1, U9.54 (PC1)
unnamed: TP16.1, U9.55 (PC2)
unnamed: TP17.1, U9.56 (PC3)
unnamed: TP18.1, U9.57 (PC4)
unnamed: TP19.1, U9.58 (PC5)
unnamed: TP20.1, U9.59 (PC6)
unnamed: TP21.1, U9.60 (PC7)
unnamed: TP22.1, U9.2 (PE0)
unnamed: TP23.1, U9.3 (PE1)
unnamed: TP24.1, U9.4 (PE2)
unnamed: TP25.1, U9.5 (PE3)
unnamed: TP26.1, U9.6 (PE4)
unnamed: TP27.1, U9.7 (PE5)
unnamed: TP28.1, U9.8 (PE6)
unnamed: TP29.1, U9.9 (PE7)
unnamed: TP30.1, U9.97 (PF0)
unnamed: TP32.1, U9.96 (PF1)
unnamed: TP34.1, U9.95 (PF2)
unnamed: TP36.1, U9.94 (PF3)
unnamed: TP33.1, U9.70 (PG2)
unnamed: TP35.1, U9.28 (PG3)
unnamed: TP37.1, U9.29 (PG4)
unnamed: TP38.1, U9.1 (PG5)
unnamed: C25.2, U9.34 (XTAL1), Y1.2
unnamed: C26.2, U9.33 (XTAL2), Y1.1
PD5: D10.3 (DIN), J10.6, U9.48 (PD5)
VDDA: C24.1, L3.2, U9.100 (AVCC)

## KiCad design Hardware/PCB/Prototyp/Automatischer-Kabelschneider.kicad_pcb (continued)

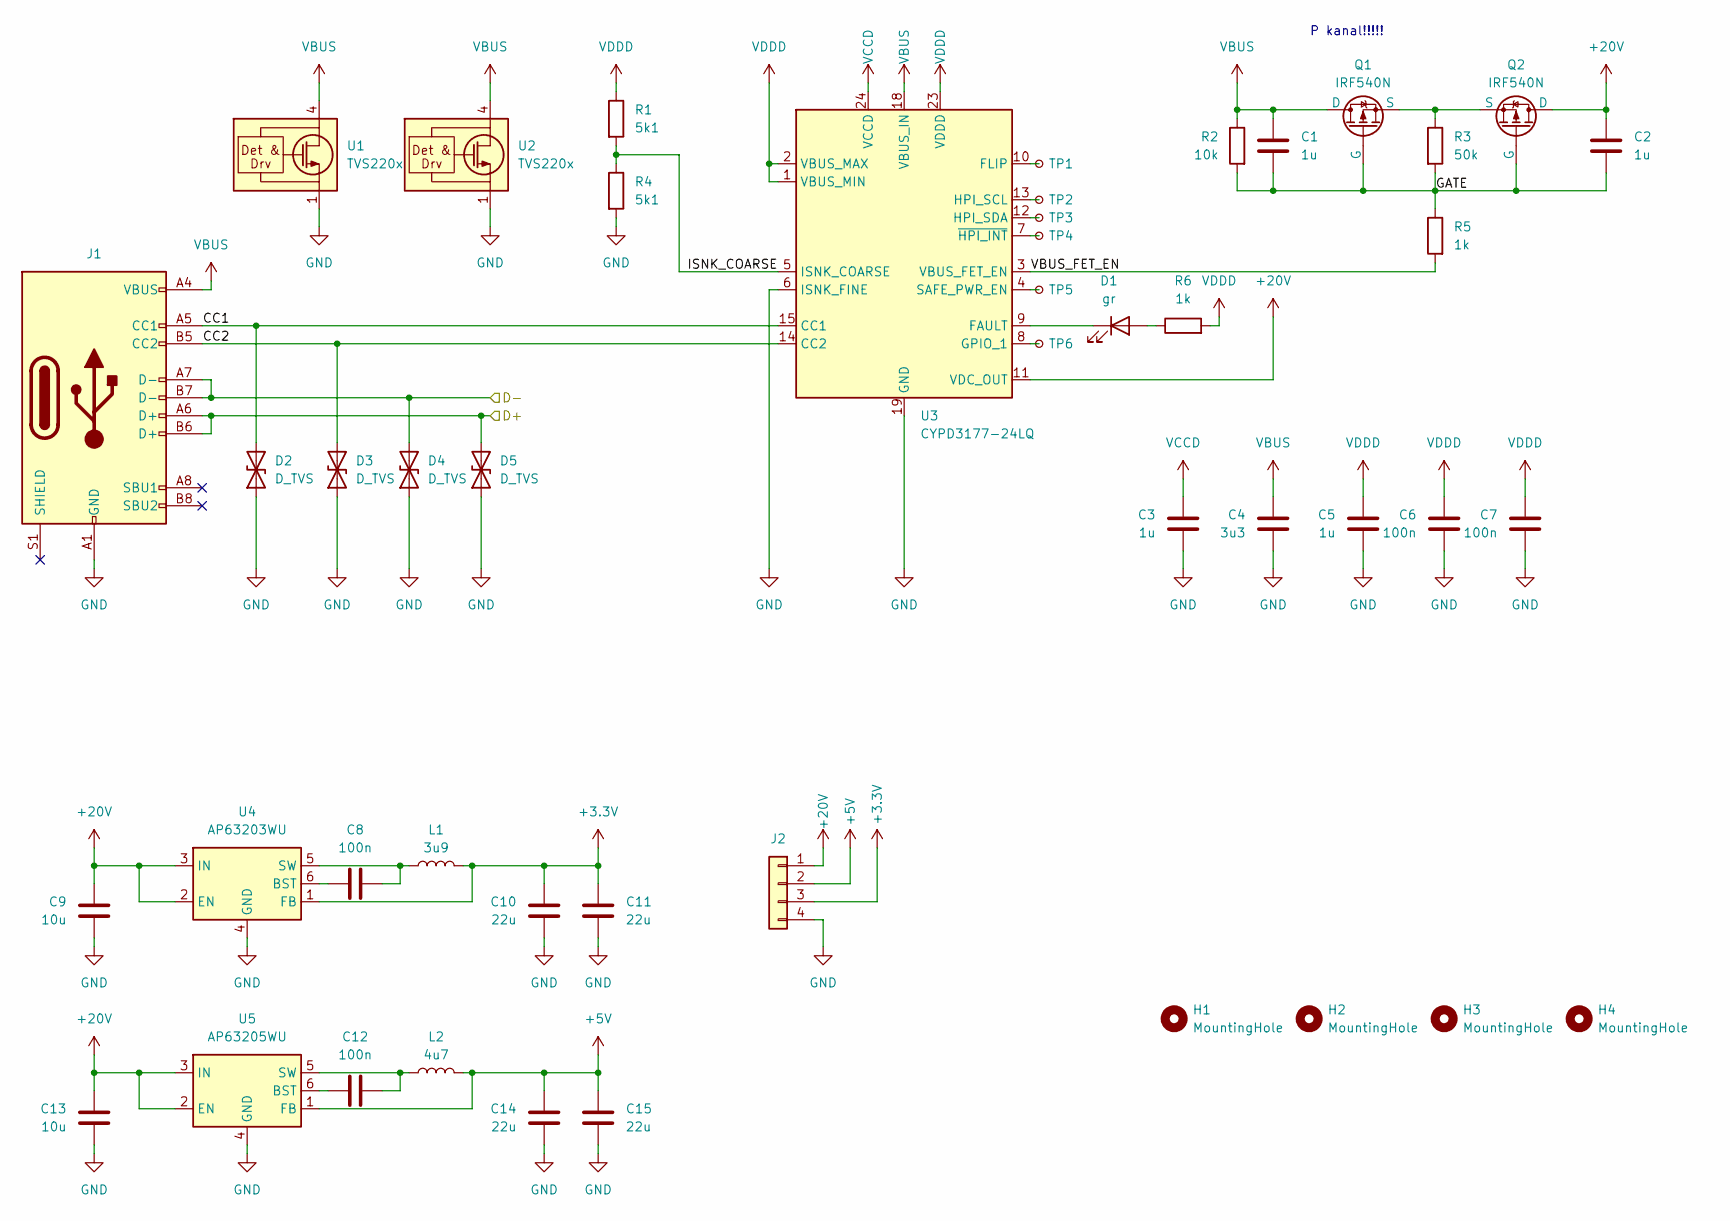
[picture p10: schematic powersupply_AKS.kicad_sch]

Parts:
C1, C2, C3, C5: 1u; C_0805_2012Metric
C4: 3u3; C_0805_2012Metric
C6, C7, C8, C12: 100n; C_0805_2012Metric
C9, C13: 10u; C_0805_2012Metric
C10, C11, C14, C15: 22u; C_0805_2012Metric
D1: gr; D_0805_2012Metric
D2, D3, D4, D5: D_TVS; D_0603_1608Metric
H1, H2, H3, H4: MountingHole; MountingHole_3.2mm_M3
J1: USB_C_Receptacle_USB2.0_16P; USB_C_Receptacle_GCT_USB4105-xx-A_16P_TopMnt_Horizontal
J2: Conn_01x04; PhoenixContact_GMSTBA_2,5_4-G-7,62_1x04_P7.62mm_Horizontal
L1: 3u9; L_Wurth_WE-LQSH-4020
L2: 4u7; L_Wurth_WE-LQSH-4020
Q1, Q2: IRF540N; TO-220-3_Vertical
R1, R4: 5k1; R_0805_2012Metric
R2: 10k; R_0805_2012Metric
R3: 50k; R_0805_2012Metric
R5, R6: 1k; R_0805_2012Metric
TP1, TP2, TP3, TP4, TP5, TP6: TestPoint_Small; TestPoint_Pad_D1.0mm
U1, U2: TVS220x; WSON-6-1EP_2x2mm_P0.65mm_EP1x1.6mm
U3: CYPD3177-24LQ; QFN-24-1EP_4x4mm_P0.5mm_EP2.75x2.75mm
U4: AP63203WU; TSOT-23-6
U5: AP63205WU; TSOT-23-6

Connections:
+3.3V: C10.1, C11.1, J2.3, L1.2, U4.1 (FB); also elsewhere on the board
+5V: C14.1, C15.1, J2.2, L2.2, U5.1 (FB); also elsewhere on the board
/Main Microcontroller/D+: D5.2 (A2), J1.A6 (D+), J1.B6 (D+); also elsewhere on the board
/Main Microcontroller/D-: D4.2 (A2), J1.A7 (D-), J1.B7 (D-); also elsewhere on the board
/Powersupply_AKS/CC1: D2.2 (A2), J1.A5 (CC1), U3.15 (CC1)
/Powersupply_AKS/CC2: D3.2 (A2), J1.B5 (CC2), U3.14 (CC2)
/Powersupply_AKS/ISNK_COARSE: R1.2, R4.1, U3.5 (ISNK_COARSE)
/Powersupply_AKS/VBUS_FET_EN: R5.2, U3.3 (VBUS_FET_EN)
GND: C3.2, C4.2, C5.2, C6.2, C7.2, C9.2, C10.2, C11.2, C13.2, C14.2, C15.2, D2.1 (A1), D3.1 (A1), D4.1 (A1), D5.1 (A1), J1.A1 (GND), J1.A12 (GND), J1.B1 (GND), J1.B12 (GND), J2.4, R4.2, U1.1 (GND), U1.2 (GND), U1.3 (GND), U1.7 (GND), U2.1 (GND), U2.2 (GND), U2.3 (GND), U2.7 (GND), U3.6 (ISNK_FINE), U3.19 (GND), U3.22 (GND), U3.25 (GND), U4.4 (GND), U5.4 (GND); also elsewhere on the board
unnamed: D1.2 (A), R6.1
unnamed: D1.1 (K), U3.9 (FAULT)
unnamed: Q1.3 (S), Q2.3 (S), R3.1
unnamed: TP1.1, U3.10 (FLIP)
unnamed: TP6.1, U3.8 (GPIO_1)
unnamed: TP2.1, U3.13 (HPI_SCL)
unnamed: TP3.1, U3.12 (HPI_SDA)
unnamed: TP5.1, U3.4 (SAFE_PWR_EN)
unnamed: TP4.1, U3.7 (~HPI_INT)
unnamed: C8.2, U4.6 (BST)
unnamed: C8.1, L1.1, U4.5 (SW)
unnamed: C12.2, U5.6 (BST)
unnamed: C12.1, L2.1, U5.5 (SW)
VCCD: C3.1, U3.24 (VCCD)
VDDD: C5.1, C6.1, C7.1, R1.1, R6.2, U3.1 (VBUS_MIN), U3.2 (VBUS_MAX), U3.23 (VDDD)

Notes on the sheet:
P kanal!!!!!

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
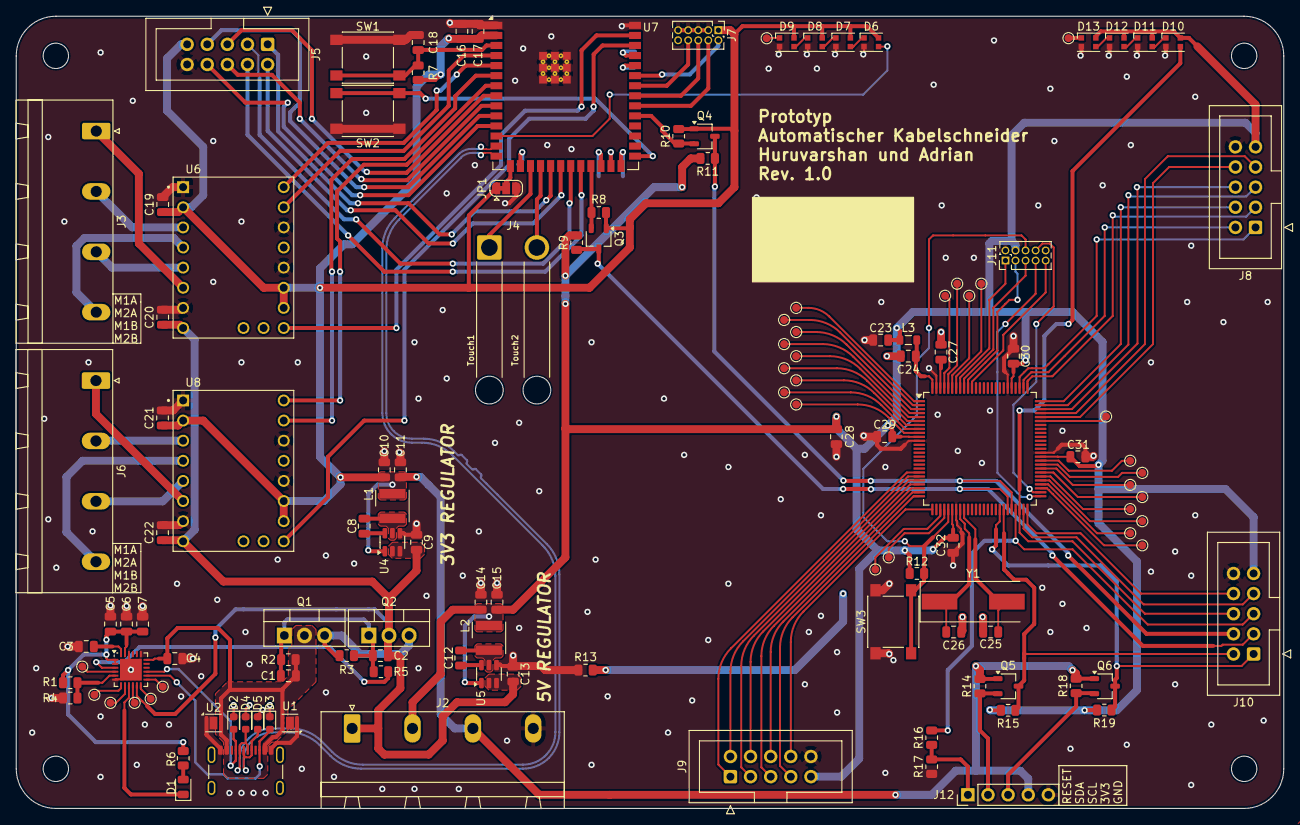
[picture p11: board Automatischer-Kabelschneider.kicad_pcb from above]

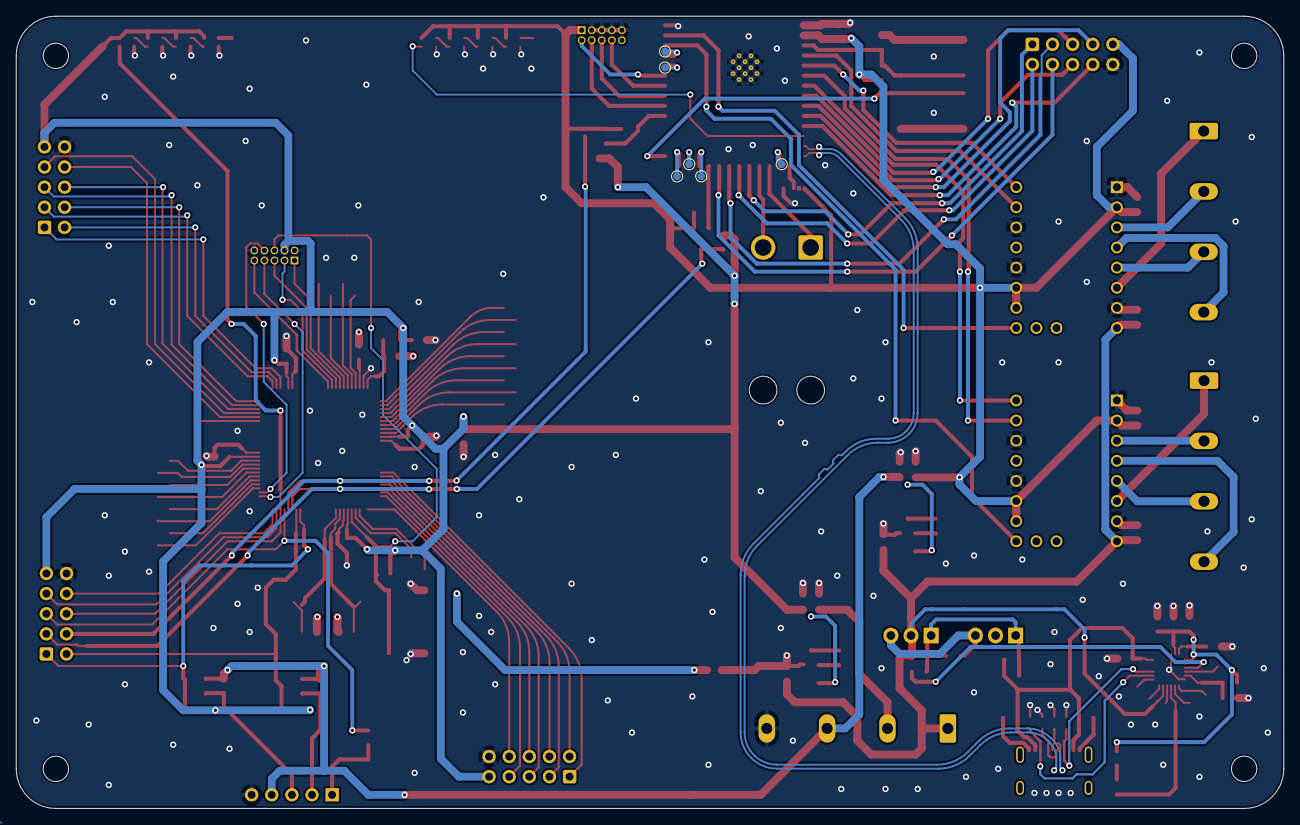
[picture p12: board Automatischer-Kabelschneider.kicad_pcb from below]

Board: 4 copper layers, 160.0 x 100.0 mm, 141 parts (6 on the bottom side), 138 nets.

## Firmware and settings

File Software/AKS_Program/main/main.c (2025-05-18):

#include <stdio.h>
#include "freertos/FreeRTOS.h"
#include "freertos/task.h"
#include "driver/rmt_tx.h"
#include "driver/gpio.h"
#include "esp_log.h"
#include "esp_random.h"
#include "math.h"
#include "esp_wifi.h"
#include "nvs_flash.h"
#include "esp_now.h"
#include "esp_mac.h"
#include "string.h"
#include "stepper_motor_encoder.h"
#include "led_strip.h" 
#include "driver/touch_pad.h"

#define TOUCH_GPIO 1 // GPIO for touch sensor
#define THRESHOLD 80000 // Threshold for touch sensor
#define LED_STRIP_GPIO 14 // GPIO for LED strip
#define LED_STRIP_NUM_LEDS 12 // Number of LEDs in the strip

void EspNowTask(void *pvParameters); 
void StepperTask(void *pvParameters); 
void SafetyTask(void *pvParameters);
void LedTask(void *pvParameters); 

char *mac_to_str(char *buffer, uint8_t *mac);
void on_sent(const uint8_t *mac_addr, esp_now_send_status_t status); 
void on_receive(const esp_now_recv_info_t *esp_now_info, const uint8_t *data, int data_len); 



SemaphoreHandle_t feederStructMutex; 
SemaphoreHandle_t triggerSemaphore;

// Structure for incoming data from the display unit
struct feeder_in_t {
    uint16_t id; // ID from the display unit. Gets from display unit (R)
    uint16_t setAmount; // The set amount configured by the user. Gets from display unit (R) 
    uint16_t setLength; // The set length configured by the user. Gets from display unit (R)
    bool flagStartStop; // Start/Stop flag. Defines if it should stop or continue working. Gets from display unit (R/W) (1 = start, 0 = stop)
    bool flagAbort; // Abort flag. Defines if the job should get aborted. Gets from display unit (R) (1 = abort, 0 = no abort)
} feeder_incoming;

// Structure for outgoing data to the display unit 
struct feeder_out_t {
    uint16_t id; // Sends to display unit (W)
    uint16_t processedAmount; // Sends to display unit (W) 
    bool flagStartStop; // Sends to display unit (W) (1 = start, 0 = stop)
    bool flagAbort; // Sends to display unit (W) (1 = abort, 0 = no abort)
    bool runOut; // Sends to display unit (W) (1 = run out, 0 = no run out)
} feeder_outgoing; 


void app_main(void)
{
    uint8_t my_mac[6];
    char my_mac_str[13];

    feederStructMutex = xSemaphoreCreateMutex(); 
    triggerSemaphore = xSemaphoreCreateBinary(); 

    //feeder.incoming.id = //set to gpio mäuseklavier
    feeder_incoming.setAmount = 0; // Edit to 0 later
    feeder_incoming.setLength = 0; // Edit to 0 later
    feeder_incoming.flagStartStop = 0; 
    feeder_incoming.flagAbort = 0; 

    //feeder_outgoing.id //set to gpio mäuseklavier
    feeder_outgoing.processedAmount = 0; 
    feeder_outgoing.flagStartStop = 1; 
    feeder_outgoing.flagAbort = 0;
    feeder_outgoing.runOut = 0;



    xTaskCreate(StepperTask, "StepperTask", 8192, NULL, 2, NULL);
    xTaskCreate(EspNowTask, "EspNowTask", 8192, NULL, 2, NULL);
    xTaskCreate(SafetyTask, "SafetyTask", 8192, NULL, 3, NULL);
    xTaskCreate(LedTask, "LedTask", 8192, NULL, 1, NULL);
}



void EspNowTask(void *pvParameters){
    uint8_t macDisplay[6] = {0xe4, 0x65, 0xb8, 0x7e, 0x27, 0x98}; // MAC address of the display unit 
    uint8_t my_mac[6];
    char my_mac_str[13];
    // Define a local instance of the feeder_out_t struct for transmission
    struct feeder_out_t feeder_outgoing_data;
    
    esp_efuse_mac_get_default(my_mac);
    ESP_LOGI("MAC_ADDRESS", "My mac %s", mac_to_str(my_mac_str, my_mac));
    
    // Initialize NVS and networking components
    nvs_flash_init();
    ESP_ERROR_CHECK(esp_netif_init());
    ESP_ERROR_CHECK(esp_event_loop_create_default());
    wifi_init_config_t cfg = WIFI_INIT_CONFIG_DEFAULT();
    ESP_ERROR_CHECK(esp_wifi_init(&cfg));
    ESP_ERROR_CHECK(esp_wifi_set_storage(WIFI_STORAGE_RAM));
    ESP_ERROR_CHECK(esp_wifi_set_mode(WIFI_MODE_STA));
    ESP_ERROR_CHECK(esp_wifi_start());
    
    // Initialize ESP-NOW
    ESP_ERROR_CHECK(esp_now_init());
    ESP_ERROR_CHECK(esp_now_register_send_cb(on_sent));
    ESP_ERROR_CHECK(esp_now_register_recv_cb(on_receive));
    
    // Configure peer (display unit)
    esp_now_peer_info_t peer;
    memset(&peer, 0, sizeof(esp_now_peer_info_t));
    memcpy(peer.peer_addr, macDisplay, 6);
    peer.channel = 0;  
    peer.ifidx = ESP_IF_WIFI_STA;
    peer.encrypt = false;
    ESP_ERROR_CHECK(esp_now_add_peer(&peer));

    xSemaphoreTake(feederStructMutex, portMAX_DELAY);

    // Copy the global feeder_outgoing struct data to local struct
    // (assuming feeder_outgoing is a global variable)
    memcpy(&feeder_outgoing_data, &feeder_outgoing, sizeof(struct feeder_out_t));

    // Log the data being sent (optional)
    ESP_LOGI("ESP_NOW", "Sending data: id=%d, processed=%d, start/stop=%d, abort=%d, runOut=%d", 
    feeder_outgoing_data.id, 
    feeder_outgoing_data.processedAmount,
    feeder_outgoing_data.flagStartStop,
    feeder_outgoing_data.flagAbort,
    feeder_outgoing_data.runOut);

    // Send the struct directly through ESP-NOW
    ESP_ERROR_CHECK(esp_now_send(NULL, (uint8_t *)&feeder_outgoing_data, sizeof(struct feeder_out_t)));

    // Release the mutex
    xSemaphoreGive(feederStructMutex);
    
    while (1)
    {
        // Wait for trigger semaphore from another task
        if(xSemaphoreTake(triggerSemaphore, portMAX_DELAY) == pdTRUE){
            // Access shared data with mutex protection
            xSemaphoreTake(feederStructMutex, portMAX_DELAY);
            
            // Copy the global feeder_outgoing struct data to local struct
            // (assuming feeder_outgoing is a global variable)
            memcpy(&feeder_outgoing_data, &feeder_outgoing, sizeof(struct feeder_out_t));
            
            // Log the data being sent (optional)
            ESP_LOGI("ESP_NOW", "Sending data: id=%d, processed=%d, start/stop=%d, abort=%d, runOut=%d", 
                   feeder_outgoing_data.id, 
                   feeder_outgoing_data.processedAmount,
                   feeder_outgoing_data.flagStartStop,
                   feeder_outgoing_data.flagAbort,
                   feeder_outgoing_data.runOut);
            
            // Send the struct directly through ESP-NOW
            ESP_ERROR_CHECK(esp_now_send(NULL, (uint8_t *)&feeder_outgoing_data, sizeof(struct feeder_out_t)));
            
            // Release the mutex
            xSemaphoreGive(feederStructMutex);
           
            // Delay to prevent flooding the network
            //vTaskDelay(pdMS_TO_TICKS(1000));
        }
    }
}

void on_sent(const uint8_t *mac_addr, esp_now_send_status_t status)
{
    xSemaphoreTake(feederStructMutex, portMAX_DELAY); //Take MUTEX to access the feeder struct

    char buffer[13];
    switch (status)
    {
    case ESP_NOW_SEND_SUCCESS:
        ESP_LOGI("MAC_ADDRESS", "message sent to %s", mac_to_str(buffer, (uint8_t *)mac_addr));
        break;
    case ESP_NOW_SEND_FAIL:
        ESP_LOGE("MAC_ADDRESS", "message sent to %s failed", mac_to_str(buffer, (uint8_t *)mac_addr));
        break;
    }

    xSemaphoreGive(feederStructMutex); //Give MUTEX to allow other tasks to access the feeder struct
}

void on_receive(const esp_now_recv_info_t *esp_now_info, const uint8_t *data, int data_len)
{
    // Take mutex to safely access the shared feeder struct
    xSemaphoreTake(feederStructMutex, portMAX_DELAY);
   
    // Log the MAC address of the sender
    ESP_LOGI("MAC_ADDRESS", "Got message from " MACSTR, MAC2STR(esp_now_info->src_addr));
   
    // Check if the data size matches our expected struct size
    if (data_len == sizeof(struct feeder_in_t)) {
        struct feeder_in_t temp_incoming;
       
        // Cast the received data to our temp struct
        memcpy(&temp_incoming, data, sizeof(struct feeder_in_t));
        
        // Check if this is a new job (different ID or different setAmount)
        if (temp_incoming.id != feeder_incoming.id || 
            temp_incoming.setAmount != feeder_incoming.setAmount) {
            // New job detected, reset the processed amount counter
            feeder_outgoing.processedAmount = 0;
            ESP_LOGI("ESP_NOW", "New job detected. Resetting processed amount.");
        }
        // The original check is still useful for when the job completes
        else if (feeder_outgoing.processedAmount >= feeder_incoming.setAmount) {
            // Job is complete, reset the counter for the new job
            feeder_outgoing.processedAmount = 0;
            ESP_LOGI("ESP_NOW", "Previous job complete. Resetting processed amount for new job.");
        }
       
        // Now copy to our global struct
        memcpy(&feeder_incoming, &temp_incoming, sizeof(struct feeder_in_t));
       
        // Log the received data for debugging
        ESP_LOGI("ESP_NOW", "Received struct data: id=%d, setAmount=%d, setLength=%d, startStop=%d, abort=%d",
               feeder_incoming.id,
               feeder_incoming.setAmount,
               feeder_incoming.setLength,
               feeder_incoming.flagStartStop,
               feeder_incoming.flagAbort);
    } else {
        // Handle unexpected data size
        ESP_LOGW("ESP_NOW", "Received data with unexpected size: %d bytes (expected %d bytes)",
                data_len, sizeof(struct feeder_in_t));
    }
   
    // Release the mutex
    xSemaphoreGive(feederStructMutex);
}

char *mac_to_str(char *buffer, uint8_t *mac)
{
    // Make sure the buffer is properly initialized
    memset(buffer, 0, 18);  // Clear buffer (allocate at least 18 bytes for the buffer)
    
    // Format MAC address with proper null termination
    snprintf(buffer, 18, MACSTR, MAC2STR(mac));
    
    return buffer;
}

void StepperTask(void *pvParameters){
    // Tag for logging messages from the Stepper Task
    static const char *STEPPER_TAG = "STEPPER TASK";

    // Initialize GPIO pins for EN (Enable), DIR (Direction), and Microstep settings (MS1, MS2)
    ESP_LOGI(STEPPER_TAG, "Initialize EN + DIR GPIO");
    gpio_config_t en_dir_gpio_config = {
        .mode = GPIO_MODE_OUTPUT, // Set as output mode
        .intr_type = GPIO_INTR_DISABLE, // Disable interrupts
        .pin_bit_mask = 1ULL << STEP_MOTOR_GPIO_DIR | 1ULL << STEP_MOTOR_GPIO_EN | 1ULL << STEP_MOTOR_GPIO_MS1 | 1ULL << STEP_MOTOR_GPIO_MS2, // GPIO pins for motor control
    };
    ESP_ERROR_CHECK(gpio_config(&en_dir_gpio_config));

    // Set microstepping mode (MS1 and MS2 pins)
    gpio_set_level(STEP_MOTOR_GPIO_MS1, 1); // Enable MS1
    gpio_set_level(STEP_MOTOR_GPIO_MS2, 1); // Enable MS2

    // Create RMT (Remote Control) TX channel for stepper motor control
    ESP_LOGI(STEPPER_TAG, "Create RMT TX channel");
    rmt_channel_handle_t motor_chan = NULL;
    rmt_tx_channel_config_t tx_chan_config = {
        .clk_src = RMT_CLK_SRC_DEFAULT, // Select default clock source
        .gpio_num = STEP_MOTOR_GPIO_STEP, // GPIO pin for STEP signal
        .mem_block_symbols = 64, // Memory block size
        .resolution_hz = STEP_MOTOR_RESOLUTION_HZ, // RMT resolution in Hz
        .trans_queue_depth = 10, // Transaction queue depth
    };
    ESP_ERROR_CHECK(rmt_new_tx_channel(&tx_chan_config, &motor_chan));

    // Set motor spin direction
    ESP_LOGI(STEPPER_TAG, "Set spin direction");
    gpio_set_level(STEP_MOTOR_GPIO_DIR, STEP_MOTOR_SPIN_DIR_CLOCKWISE); // Set direction to clockwise

    // Enable the stepper motor
    ESP_LOGI(STEPPER_TAG, "Enable step motor");
    gpio_set_level(STEP_MOTOR_GPIO_EN, STEP_MOTOR_ENABLE_LEVEL); // Enable motor driver

    // Create motor encoders for acceleration, uniform speed, and deceleration phases
    ESP_LOGI(STEPPER_TAG, "Create motor encoders");

    // Encoder for acceleration phase
    stepper_motor_curve_encoder_config_t accel_encoder_config = {
        .resolution = STEP_MOTOR_RESOLUTION_HZ, // Encoder resolution
        .sample_points = 500, // Number of sample points
        .start_freq_hz = 500, // Starting frequency in Hz
        .end_freq_hz = STEP_MOTOR_ACCEL_DECEL_FREQ, // Ending frequency in Hz
    };
    rmt_encoder_handle_t accel_motor_encoder = NULL;
    ESP_ERROR_CHECK(rmt_new_stepper_motor_curve_encoder(&accel_encoder_config, &accel_motor_encoder));

    // Encoder for uniform speed phase
    stepper_motor_uniform_encoder_config_t uniform_encoder_config = {
        .resolution = STEP_MOTOR_RESOLUTION_HZ, // Encoder resolution
    };
    rmt_encoder_handle_t uniform_motor_encoder = NULL;
    ESP_ERROR_CHECK(rmt_new_stepper_motor_uniform_encoder(&uniform_encoder_config, &uniform_motor_encoder));

    // Encoder for deceleration phase
    stepper_motor_curve_encoder_config_t decel_encoder_config = {
        .resolution = STEP_MOTOR_RESOLUTION_HZ, // Encoder resolution
        .sample_points = 500, // Number of sample points
        .start_freq_hz = STEP_MOTOR_ACCEL_DECEL_FREQ, // Starting frequency in Hz
        .end_freq_hz = 500, // Ending frequency in Hz
    };
    rmt_encoder_handle_t decel_motor_encoder = NULL;
    ESP_ERROR_CHECK(rmt_new_stepper_motor_curve_encoder(&decel_encoder_config, &decel_motor_encoder));

    // Enable the RMT channel
    ESP_LOGI(STEPPER_TAG, "Enable RMT channel");
    ESP_ERROR_CHECK(rmt_enable(motor_chan));

    // Log the motor spin configuration
    ESP_LOGI(STEPPER_TAG, "Spin motor for 6000 steps: 500 accel + 5000 uniform + 500 decel");

    // Configure RMT transmission settings
    rmt_transmit_config_t tx_config = {
        .loop_count = 0, // No looping
    };

    // Define constants for acceleration, uniform speed, and deceleration phases
    const static uint32_t accel_samples = STEP_MOTOR_ACCEL_DECEL_SAMPLES; // Number of acceleration samples
    const static uint32_t uniform_speed_hz = STEP_MOTOR_ACCEL_DECEL_FREQ; // Uniform speed frequency in Hz
    const static uint32_t decel_samples = STEP_MOTOR_ACCEL_DECEL_SAMPLES; // Number of deceleration samples

    // Log stepper motor parameters
    ESP_LOGI(STEPPER_TAG, "Steps per millimeter: %d", STEPS_PER_mm); 
    ESP_LOGI(STEPPER_TAG, "Steps per micrometer: %d", STEPS_PER_um); 

    
    while (1)
    {
        xSemaphoreTake(feederStructMutex, portMAX_DELAY); //Take MUTEX to access the feeder struct

        if((feeder_incoming.setAmount > feeder_outgoing.processedAmount) && (feeder_incoming.flagStartStop && !feeder_incoming.flagAbort && feeder_outgoing.flagStartStop && !feeder_outgoing.flagAbort && !feeder_outgoing.runOut)){
            // acceleration phase
            tx_config.loop_count = 0; 
            ESP_ERROR_CHECK(rmt_transmit(motor_chan, accel_motor_encoder, &accel_samples, sizeof(accel_samples), &tx_config));

            // uniform phase
            //tx_config.loop_count = counter;
            tx_config.loop_count = (feeder_incoming.setLength * (STEPS_PER_um/1000)) - STEP_MOTOR_ACCEL_DECEL_SAMPLES;
            ESP_ERROR_CHECK(rmt_transmit(motor_chan, uniform_motor_encoder, &uniform_speed_hz, sizeof(uniform_speed_hz), &tx_config));

            // deceleration phase
            tx_config.loop_count = 0;
            ESP_ERROR_CHECK(rmt_transmit(motor_chan, decel_motor_encoder, &decel_samples, sizeof(decel_samples), &tx_config));
            // wait all transactions finished
            ESP_ERROR_CHECK(rmt_tx_wait_all_done(motor_chan, -1));



            feeder_outgoing.processedAmount ++; 
            ESP_LOGI(STEPPER_TAG, "Feeding finished. Processed amount: %d", feeder_outgoing.processedAmount);
            ESP_LOGI(STEPPER_TAG, "Remaining amount: %d", feeder_incoming.setAmount - feeder_outgoing.processedAmount); 

            xSemaphoreGive(triggerSemaphore); //Give trigger to the ESP-NOW task to send the data to the display unit
        } //else dann motor off

        xSemaphoreGive(feederStructMutex); //Give MUTEX to allow other tasks to access the feeder struct
        vTaskDelay(pdMS_TO_TICKS(2500)); //Delay the task for 2 seconds  
    }
}

void SafetyTask(void *pvParameters){ //auch für runout benutzen
    touch_pad_init();
    touch_pad_config(TOUCH_GPIO); 
    touch_pad_denoise_t denoise = {
        /* The bits to be cancelled are determined according to the noise level. */
        .grade = TOUCH_PAD_DENOISE_BIT4,
        .cap_level = TOUCH_PAD_DENOISE_CAP_L4,
    };
    touch_pad_denoise_set_config(&denoise);
    touch_pad_denoise_enable();
    /* Enable touch sensor clock. Work mode is "timer trigger". */
    touch_pad_set_fsm_mode(TOUCH_FSM_MODE_TIMER);
    touch_pad_fsm_start();
    

    uint32_t touch_value = 0;
    
    vTaskDelay(100 / portTICK_PERIOD_MS);
    
    while (1)
    {
        xSemaphoreTake(feederStructMutex, portMAX_DELAY); // Take MUTEX to access the feeder struct
        touch_pad_read_raw_data(TOUCH_GPIO, &touch_value);    // read raw data.
        //ESP_LOGI("TOUCH", "Touch value: %" PRIu32, touch_value);

        if (touch_value > THRESHOLD) {
            ESP_LOGW("TOUCH", "Touch detected! Touch value: %" PRIu32, touch_value);

            feeder_outgoing.flagAbort = 1; // Set flagAbort to 1
            
            // Abort the stepper motor task and disabling the motor
            gpio_set_level(STEP_MOTOR_GPIO_EN, !STEP_MOTOR_ENABLE_LEVEL);

            xSemaphoreGive(triggerSemaphore); // Trigger the ESP-NOW task
        }

        xSemaphoreGive(feederStructMutex); // Release MUTEX
        vTaskDelay(pdMS_TO_TICKS(100)); 
    }
}

void LedTask(void *pvParameters){

    led_strip_config_t strip_config = {
    .strip_gpio_num = LED_STRIP_GPIO,  // The GPIO that connected to the LED strip's data line
    .max_leds = LED_STRIP_NUM_LEDS,                 // The number of LEDs in the strip,
    .led_model = LED_MODEL_WS2812, // LED strip model, it determines the bit timing
    .color_component_format = LED_STRIP_COLOR_COMPONENT_FMT_GRB, // The color component format is G-R-B
    .flags = {
        .invert_out = false, // don't invert the output signal
        }
    };

    /// RMT backend specific configuration
    led_strip_rmt_config_t rmt_config = {
        .clk_src = RMT_CLK_SRC_DEFAULT,    // different clock source can lead to different power consumption
        .resolution_hz = 10 * 1000 * 1000, // RMT counter clock frequency: 10MHz
        .mem_block_symbols = 64,           // the memory size of each RMT channel, in words (4 bytes)
        .flags = {
            .with_dma = false, // DMA feature is available on chips like ESP32-S3/P4
        }
    };

    /// Create the LED strip object
    led_strip_handle_t led_strip;
    ESP_ERROR_CHECK(led_strip_new_rmt_device(&strip_config, &rmt_config, &led_strip));

    
    static bool led_state = false; // For flashing behavior
    
    while (1)
    {   
        xSemaphoreTake(feederStructMutex, portMAX_DELAY); // Take MUTEX to access the feeder struct
        for (int i = 0; i < LED_STRIP_NUM_LEDS; i++) {
            if (feeder_incoming.flagAbort || feeder_outgoing.runOut || feeder_outgoing.flagAbort) {
            // Flash red (abort or runout)
            if (led_state) {
                ESP_ERROR_CHECK(led_strip_set_pixel(led_strip, i, 255, 0, 0)); // Red
            } else {
                ESP_ERROR_CHECK(led_strip_set_pixel(led_strip, i, 0, 0, 0)); // Turn off LEDs
            }
            } else {
            switch (feeder_incoming.flagStartStop) {
                case 0: // No job or paused
                // Solid green (no job)
                ESP_ERROR_CHECK(led_strip_set_pixel(led_strip, i, 0, 255, 0)); // Green
                break;
    
                case 1: // Job in progress
                // Solid yellow
                ESP_ERROR_CHECK(led_strip_set_pixel(led_strip, i, 255, 255, 0)); // Yellow
                break;
    
                default:
                ESP_LOGW("LED_TASK", "Unexpected flagStartStop value: %d", feeder_incoming.flagStartStop);
                break;
            }
            }
        }
    
        ESP_ERROR_CHECK(led_strip_refresh(led_strip)); // Refresh the LED strip
        xSemaphoreGive(feederStructMutex); // Release MUTEX
    
        led_state = !led_state; // Toggle the LED state for flashing behavior
        vTaskDelay(pdMS_TO_TICKS(500)); // Delay for 1 second
    }
}

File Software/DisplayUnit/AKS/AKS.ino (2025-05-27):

/*  Rui Santos & Sara Santos - Random Nerd Tutorials
    THIS EXAMPLE WAS TESTED WITH THE FOLLOWING HARDWARE:
      REGULAR ESP32 Dev Board + 2.8 inch 240x320 TFT Display: https://makeradvisor.com/tools/2-8-inch-ili9341-tft-240x320/ and https://makeradvisor.com/tools/esp32-dev-board-wi-fi-bluetooth/
      SET UP INSTRUCTIONS: https://RandomNerdTutorials.com/esp32-tft/
    Permission is hereby granted, free of charge, to any person obtaining a copy of this software and associated documentation files.
    The above copyright notice and this permission notice shall be included in all copies or substantial portions of the Software.
    Complete project details: https://RandomNerdTutorials.com/esp32-tft-touchscreen-on-off-button-ili9341-arduino/
*/

#include <SPI.h>

#include <esp_now.h>
#include <WiFi.h>

uint8_t broadcastAddress[] = {0x34, 0x85, 0x18, 0xa1, 0xc8, 0x78};

void EspNowTask(void *pvParameters); 
char *mac_to_str(char *buffer, uint8_t *mac); 
void on_sent(const uint8_t *mac_addr, esp_now_send_status_t status); 
void on_receive(const esp_now_recv_info_t *esp_now_info, const uint8_t *data, int data_len);
void on_receive(const uint8_t *mac, const uint8_t *incomingData, int len); 

struct display_out_t {
    uint16_t id; // ID from the display unit. Gets from display unit (w)
    uint16_t setAmount; // The set amount configured by the user. Gets from display unit (w) 
    uint16_t setLength; // The set length configured by the user. Gets from display unit (w)
    bool flagStartStop; // Start/Stop flag. Defines if it should stop or continue working. Gets from display unit (R/W) (1 = start, 0 = stop)
    bool flagAbort; // Abort flag. Defines if the job should get aborted. Gets from display unit (w) (1 = abort, 0 = no abort)
} display_outgoing;

struct display_in_t {
    uint16_t id; // Sends to display unit (W)
    uint16_t processedAmount; // Sends to display unit (W) 
    bool flagStartStop; // Sends to display unit (W) (1 = start, 0 = stop)
    bool flagAbort; // Sends to display unit (W) (1 = abort, 0 = no abort)
    bool runOut; // Sends to display unit (W) (1 = run out, 0 = no run out)
} display_incoming; 


/*  Install the "TFT_eSPI" library by Bodmer to interface with the TFT Display - https://github.com/Bodmer/TFT_eSPI
    *** IMPORTANT: User_Setup.h available on the internet will probably NOT work with the examples available at Random Nerd Tutorials ***
    *** YOU MUST USE THE User_Setup.h FILE PROVIDED IN THE LINK BELOW IN ORDER TO USE THE EXAMPLES FROM RANDOM NERD TUTORIALS ***
    FULL INSTRUCTIONS AVAILABLE ON HOW CONFIGURE THE LIBRARY: https://RandomNerdTutorials.com/esp32-tft/   */
#include <TFT_eSPI.h>

// Install the "XPT2046_Touchscreen" library by Paul Stoffregen to use the Touchscreen - https://github.com/PaulStoffregen/XPT2046_Touchscreen
// Note: this library doesn't require further configuration
#include <XPT2046_Touchscreen.h>

TFT_eSPI tft = TFT_eSPI();

// Touchscreen pins
#define XPT2046_IRQ 36   // T_IRQ
#define XPT2046_MOSI 32  // T_DIN
#define XPT2046_MISO 39  // T_OUT
#define XPT2046_CLK 25   // T_CLK
#define XPT2046_CS 33    // T_CS

SPIClass touchscreenSPI = SPIClass(VSPI);
XPT2046_Touchscreen touchscreen(XPT2046_CS, XPT2046_IRQ);

#define SCREEN_WIDTH 320
#define SCREEN_HEIGHT 240
#define FONT_SIZE 2
#define FONT_BIG 3

// Button position and size
#define FRAME_X 40
#define FRAME_Y 150
#define FRAME_W 250
#define FRAME_H 70

//4 adjust bottons pos/size
#define ADJ_W 80
#define ADJ_L 80
#define ADJL 10
#define ADJR SCREEN_WIDTH-ADJL-ADJ_W
#define ADJT 20
#define ADJB SCREEN_HEIGHT-ADJT-ADJ_W

//start button pos/size
#define START_H 60
#define START_Y ADJB+10
#define START_X ADJL+80+10
#define START_W SCREEN_WIDTH-20-ADJ_W-20-ADJ_W


//cont button pos/size
#define CONT_X FRAME_X
#define CONT_Y FRAME_Y
#define CONT_W (FRAME_W/2)-5
#define CONT_H FRAME_H

//abort button pos/size
#define ABORT_X FRAME_X+(FRAME_W/2)+5
#define ABORT_Y FRAME_Y
#define ABORT_W (FRAME_W/2)-5
#define ABORT_H FRAME_H

// Red zone size
#define REDBUTTON_X FRAME_X-10
#define REDBUTTON_Y FRAME_Y
#define REDBUTTON_W FRAME_W
#define REDBUTTON_H FRAME_H

// Green zone size
#define GREENBUTTON_X FRAME_X -10
#define GREENBUTTON_Y FRAME_Y
#define GREENBUTTON_W 120
#define GREENBUTTON_H FRAME_H


//Stop button
#define STOPBUTTON_X 

// LED Pin
#define LED_GREEN 16

// Touchscreen coordinates: (x, y) and pressure (z)
int x, y, z;

// Stores current button state
int buttonState = 0;
bool cont = false;
int lng =15;
int qty =10;
int prog=0;
int runtime=0;
int state=0;
int systime=0;
int stateo=0;
bool receive=0;
bool first=0;
bool touch=0;
int prodcounter=0;
bool sawstop=0;



// Print Touchscreen info about X, Y and Pressure (Z) on the Serial Monitor
void printTouchToSerial(int touchX, int touchY, int touchZ) {
  Serial.print("X = ");
  Serial.print(touchX);
  Serial.print(" | Y = ");
  Serial.print(touchY);
  Serial.print(" | Pressure = ");
  Serial.print(touchZ);
  Serial.println();
}


// Draw button frame
void drawFrame() {
  tft.fillRect(FRAME_X-10, FRAME_Y, FRAME_W+20, FRAME_H, TFT_BLACK);
}

void clearscreen(){
  tft.fillRect(0,0, SCREEN_WIDTH, SCREEN_HEIGHT, TFT_BLACK);
}



void drawscreensetup() {
  clearscreen();
  tft.fillRect(ADJR, ADJT, ADJ_W, ADJ_L, TFT_LIGHTGREY);
  tft.fillRect(ADJL, ADJT, ADJ_W, ADJ_L, TFT_LIGHTGREY);
  tft.fillRect(ADJL, ADJB, ADJ_W, ADJ_L, TFT_LIGHTGREY);
  tft.fillRect(ADJR, ADJB, ADJ_W, ADJ_L, TFT_LIGHTGREY);
  tft.fillRect(START_X, START_Y, START_W, START_H, TFT_GREEN);

  tft.setTextColor(TFT_BLACK);
  tft.setTextSize(FONT_BIG);
  tft.setTextDatum(MC_DATUM);

  tft.drawString("UP", (ADJL+ADJ_W/2), (ADJT+ADJ_W/2));
  tft.drawString("UP", (ADJR+ADJ_W/2), (ADJT+ADJ_W/2));
  tft.drawString("DOWN", (ADJL+ADJ_W/2), (ADJB+ADJ_W/2));
  tft.drawString("DOWN", (ADJR+ADJ_W/2), (ADJB+ADJ_W/2));
  tft.drawString("START", (SCREEN_WIDTH/2), (START_Y+START_H/2));

  tft.setTextColor(TFT_WHITE);
  tft.setTextSize(FONT_SIZE);
  tft.setTextDatum(MC_DATUM);

  tft.drawString("QTY", (ADJL+ADJ_W/2), (SCREEN_HEIGHT/2));
  tft.drawString("LNG", (ADJR+ADJ_W/2), (SCREEN_HEIGHT/2));
  tft.drawString("QTY:", ((SCREEN_WIDTH*2)/5), (80));
  tft.drawString("LNG:", ((SCREEN_WIDTH*2)/5), (100));
  tft.drawString(String(qty), ((SCREEN_WIDTH*3)/5), 80);
  tft.drawString(String(lng) + "mm", ((SCREEN_WIDTH*3)/5), 100);
}
  
void drawscreenprod(){
  clearscreen();
  tft.setTextColor(TFT_WHITE);
  tft.setTextSize(3);
  tft.setTextDatum(MC_DATUM);
  tft.drawString(String(prog) + "/" + String(qty), (SCREEN_WIDTH/2), 100);
  tft.drawString(String(lng) + "mm", (SCREEN_WIDTH/2), 130);
  tft.setTextSize(3);
  tft.drawString("IN PRODUCTION:", (SCREEN_WIDTH/2), (60));

  tft.fillRect(FRAME_X, FRAME_Y, FRAME_W, FRAME_H, TFT_RED);
  
  tft.setTextColor(TFT_BLACK);
  tft.setTextSize(3);
  tft.drawString("PAUSE", (SCREEN_WIDTH/2), (FRAME_Y+FRAME_H/2));
}
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

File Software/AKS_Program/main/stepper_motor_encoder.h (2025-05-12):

/*
 * SPDX-FileCopyrightText: 2021-2022 Espressif Systems (Shanghai) CO LTD
 *
 * SPDX-License-Identifier: Apache-2.0
 */
#pragma once

#include <stdint.h>
#include "driver/rmt_encoder.h"

#ifdef __cplusplus
extern "C" {
#endif

// Stepper motor configuration
#define STEP_MOTOR_GPIO_EN                          4 //Enable pin of the motor driver
#define STEP_MOTOR_GPIO_DIR                         6 //Direction pin of the motor driver
#define STEP_MOTOR_GPIO_STEP                        5 //Step pin of the motor driver
#define STEP_MOTOR_GPIO_MS1                         7 //Microstep pin 1 of the motor driver
#define STEP_MOTOR_GPIO_MS2                         8 //Microstep pin 2 of the motor driver
#define STEP_MOTOR_ENABLE_LEVEL                     0 //Enable level of the motor driver; 0 for !ENABLE, 1 for ENABLE
#define STEP_MOTOR_SPIN_DIR_CLOCKWISE               0 //Spin direction of the motor driver; 1 for clockwise, 0 for counterclockwise
#define STEP_MOTOR_SPIN_DIR_COUNTERCLOCKWISE        STEP_MOTOR_SPIN_DIR_CLOCKWISE //Spin direction of the motor driver

#define STEP_MOTOR_RESOLUTION_HZ                    1000000 // Resolution of the motor driver in Hz
#define STEP_MOTOR_ACCEL_DECEL_FREQ                 3000 // Frequency of the motor driver in Hz
#define STEP_MOTOR_ACCEL_DECEL_SAMPLES              150 // Number of samples for acceleration and deceleration
#define STEP_MOTOR_FULL_ROTATION_STEPS              3200 // Number of steps for a full rotation, excluding acceleration and deceleration
#define STEP_MOTOR_FULL_ROTATION_AFTER_ACCEL_DECEL  3100 // STEP_MOTOR_FULL_ROTATION_STEPS - 2 * STEP_MOTOR_ACCEL_DECEL_SAMPLES = 3200 - 100

#define FEEDER_DIAMETER_mm                          50 // Diameter of the feeder in mm
#define FEEDER_CIRCUMFERENCE_mm                     157 // FEEDER_DIAMETER_mm * π ≈ 50 * 3.14159 = 157.08, rounded to integer
#define STEPS_PER_mm                                20 // STEP_MOTOR_FULL_ROTATION_STEPS / FEEDER_CIRCUMFERENCE_mm ≈ 3200 / 157.08 = 20.37, rounded to integer
#define STEPS_PER_um                                20372 //Steps per micrometer
#define MIN_LENGTH_mm                               5 // (STEP_MOTOR_ACCEL_DECEL_SAMPLES * 2) / STEPS_PER_mm ≈ (50 * 2) / 20 = 5

/**
 * @brief Stepper motor curve encoder configuration
 */
typedef struct {
    uint32_t resolution;    // Encoder resolution, in Hz
    uint32_t sample_points; // Sample points used for deceleration phase. Note: |end_freq_hz - start_freq_hz| >= sample_points
    uint32_t start_freq_hz; // Start frequency on the curve, in Hz
    uint32_t end_freq_hz;   // End frequency on the curve, in Hz
} stepper_motor_curve_encoder_config_t;

/**
 * @brief Stepper motor uniform encoder configuration
 */
typedef struct {
    uint32_t resolution; // Encoder resolution, in Hz
} stepper_motor_uniform_encoder_config_t;

/**
 * @brief Create stepper motor curve encoder
 *
 * @param[in] config Encoder configuration
 * @param[out] ret_encoder Returned encoder handle
 * @return
 *      - ESP_ERR_INVALID_ARG for any invalid arguments
 *      - ESP_ERR_NO_MEM out of memory when creating step motor encoder
 *      - ESP_OK if creating encoder successfully
 */
esp_err_t rmt_new_stepper_motor_curve_encoder(const stepper_motor_curve_encoder_config_t *config, rmt_encoder_handle_t *ret_encoder);

/**
 * @brief Create RMT encoder for encoding step motor uniform phase into RMT symbols
 *
 * @param[in] config Encoder configuration
 * @param[out] ret_encoder Returned encoder handle
 * @return
 *      - ESP_ERR_INVALID_ARG for any invalid arguments
 *      - ESP_ERR_NO_MEM out of memory when creating step motor encoder
 *      - ESP_OK if creating encoder successfully
 */
esp_err_t rmt_new_stepper_motor_uniform_encoder(const stepper_motor_uniform_encoder_config_t *config, rmt_encoder_handle_t *ret_encoder);

#ifdef __cplusplus
}
#endif

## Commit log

2024-03-27 Creation of prototype kicad project
    [Automatischer-Kabelschneider.kicad_pcb, Automatischer-Kabelschneider.kicad_sch, main_microcontroller_AKS.kicad_sch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]
2024-05-09 Schematic completed
    [Automatischer-Kabelschneider.kicad_pcb, Automatischer-Kabelschneider.kicad_sch, main_microcontroller_AKS.kicad_sch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]
2024-05-12 PCB finished
    [Automatischer-Kabelschneider.kicad_pcb, main_microcontroller_AKS.kicad_sch, powersupply_AKS.kicad_sch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]
2024-05-13 PCB no errors
    [Automatischer-Kabelschneider.kicad_pcb]
2024-05-15 Prototype PCB finished
    [Automatischer-Kabelschneider-B_Cu.gbr, Automatischer-Kabelschneider-B_Mask.gbr, Automatischer-Kabelschneider-B_Silks.gbr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]
2024-06-05 Changed Q1 & Q2 from NMOS to PMOS
    [powersupply_AKS.kicad_sch]
2024-07-06 First BUILD/FLASH on ESP32
2024-08-22 Stepper motor example
2024-08-30 Failed Switchreadall attempt
2024-09-10 Stepper motor working
2024-09-10 Trying out with stepper motor
2025-03-31 Restructruring files
    [20240517_Bestellliste_Mouser_Huru.xlsx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]
2025-03-31 Created V1
    [Mainboard.kicad_pcb, Mainboard.kicad_sch]
2025-04-08 Schematic v1.0 finished
    [Main.kicad_sch, Mainboard.kicad_pcb, Mainboard.kicad_sch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]
2025-04-14 finished pcb v1.0
    [Main.kicad_sch, Mainboard.kicad_pcb, PSU.kicad_sch]
2025-04-15 Gerber created
    [Mainboard-B_Cu.gbr, Mainboard-B_Mask.gbr, Mainboard-B_Paste.gbp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]
2025-05-06 board v1.0 working with bugs
    [main.c, stepper_motor_encoder.h]
2025-05-06 new driver not working
    [main.c]
2025-05-06 Revert "new driver not working"
    This reverts commit 447b560f67356a10be4f2f63d8f4024c33897fc5.
    [main.c]
2025-05-06 New driver working bad
    turns motor, but wrong speed and steps. Also doesn't block motor.
    [main.c]
2025-05-07 Old driver reimplemented
2025-05-07 added step for board
2025-05-12 Version working without led
2025-05-20 Stuff added
    [20240517_Bestellliste_Mouser_Huru.xlsx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]
2025-05-27 Added Arduino
